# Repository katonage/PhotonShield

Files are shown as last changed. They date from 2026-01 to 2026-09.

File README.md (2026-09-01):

# PhotonShield
 
**Photon Shield assembly for low-noise visual stimulation during two-photon imaging in mice**

This repository contains the 3D CAD models of the **Photon Shield**, a modular optical shielding system designed for two-photon calcium imaging experiments combined with visual stimulation in mice.
- Minimize stray-light contamination in a reproducible way
- Simple manufacturing and use
- Suitable for awake recordings
- Compatible objectives:
   - Olympus 10XSVMP 10×
   - Nikon CFI75 LWD16× W 
   - Olympus XLUMPlanFLN 20×

Detailed experimental validation, benchmarking, and use cases are described in the accompanying publication.

**Citation notice:** If you use or modify these models, please cite the following publication:  
> G. Katona, A. Slézia, A. Dávid, Á. Petik, D. Hillier, I. Ulbert, A. Kaszás <br>
> **3D Printed Photon Shield Assembly for Low-Noise Visual Stimulation During Two-Photon Imaging in Mice.** <br>
> Advanced Materials Technologies (2026): e71290. <br>
> [https://doi.org/10.1002/admt.71290](https://doi.org/10.1002/admt.71290) 

---

## Repository contents

The repository includes CAD models for:

- Headplate
- Two-part cylindrical objective shield
- Objective-mounted top shielding (“Sombrero”)
- Home-cage protection cap
- Custom holder rod and clamp

## Headholder for shield and probe wide v4mod

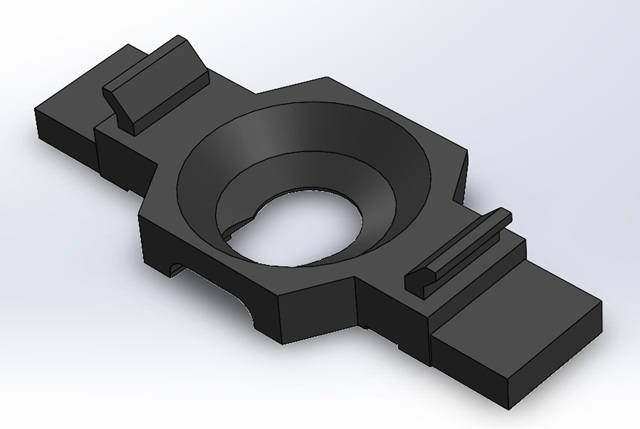
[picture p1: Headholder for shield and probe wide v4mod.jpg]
Headholder for shield and probe wide v4mod


This is the headplate with rails for mounting „Shield Back 10XSVMP v4” and „headholder cap derived v4”. Bottom has opening for a 5 mm coverslip. 

**Important:**  
Care must be taken not to put glue or cement to the top edge of the headplate.

## Shield Back 10XSVMP v4

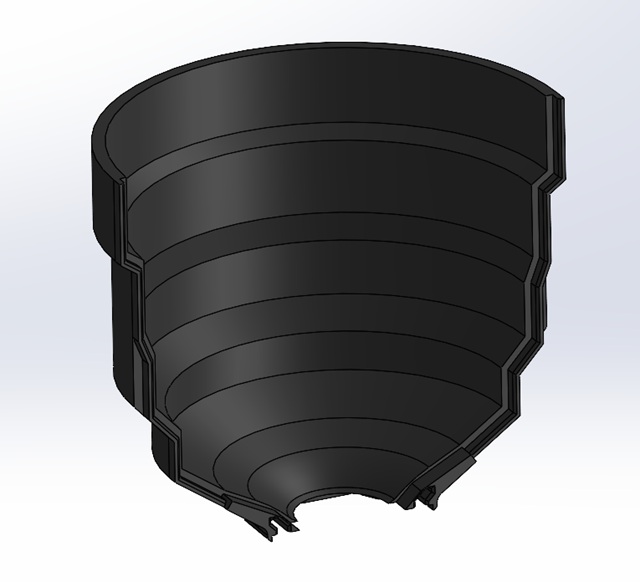
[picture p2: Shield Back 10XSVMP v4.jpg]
Shield Back 10XSVMP v4


This is one side of the shield cylinder that should be mounted first onto the headplate. It is typically mounted from the back of the animal. After mounting, immersion gel can be applied generously.

## Shield Front 10XSVMP derived v4

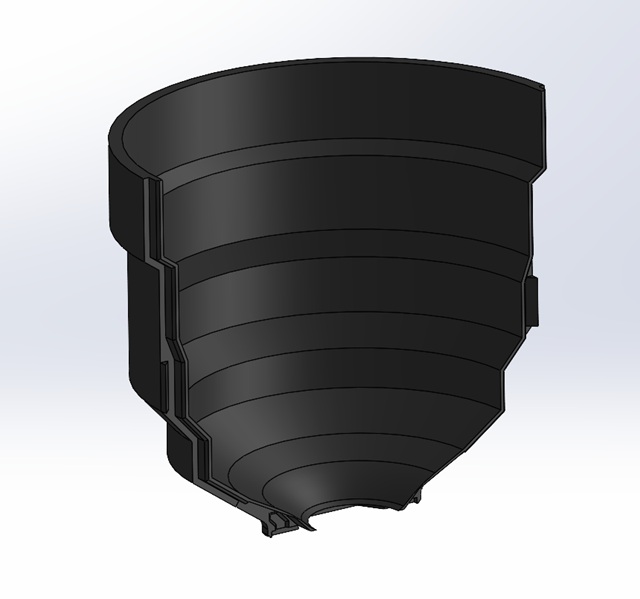
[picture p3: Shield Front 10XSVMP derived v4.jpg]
Shield Front 10XSVMP derived v4


This is the complementary part of the shield cylinder. Attach a ~20 cm long piece of black insulating tape to its outer surface, allowing it to overhang on both sides. After precise insertion, the overhanging parts are smoothed over from both sides to adhere to the other half of the shield. During the process, the microscope’s green illumination is used to make any misalignment visible.

## Headholder cap derived v4

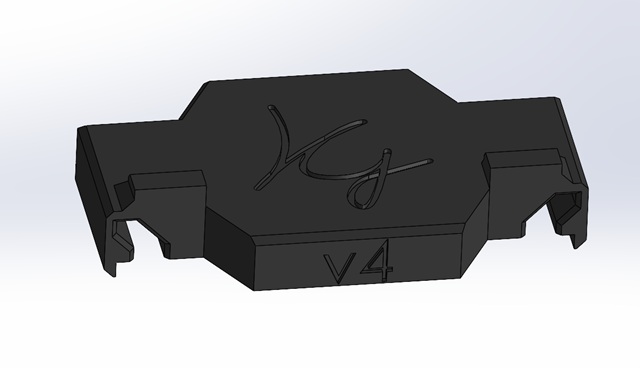
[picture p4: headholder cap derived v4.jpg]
Headholder cap derived v4


This part is fitted onto the headplate when the animal is returned to its home cage.

## Sombrero 10XSVMP v3

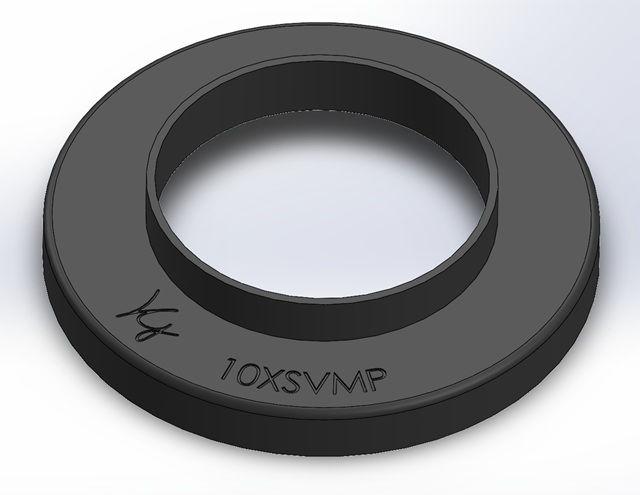
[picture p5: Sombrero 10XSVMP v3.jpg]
Sombrero 10XSVMP v3


This is the top shielding component. It must be slid onto the objective from the rear before operation.

## Sombrero XLUMPlanFLN 20x

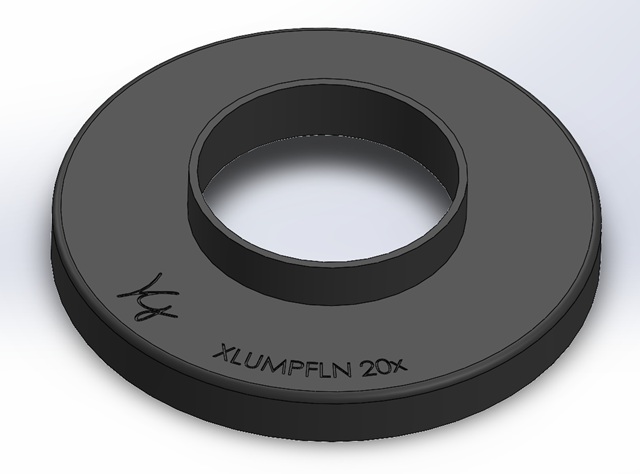
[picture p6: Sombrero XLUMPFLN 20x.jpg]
Sombrero XLUMPFLN 20x


This variant of the top shield fits both:

- **Olympus XLUMPlanFLN 20×**
- **Nikon CFI75 LWD16× W**

As with the other Sombrero design, it must be slid onto the objective from the rear prior to imaging.

## Holder rod (wide v3)

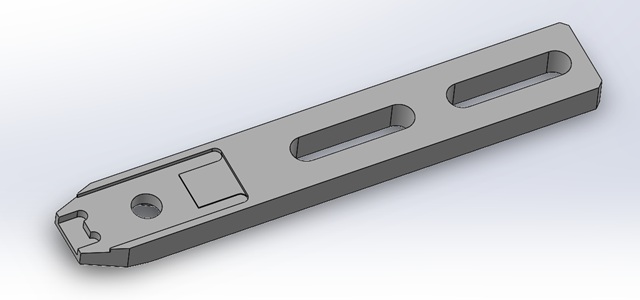
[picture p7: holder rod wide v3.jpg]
Holder rod wide v3


This is the clamp used to hold the headplate. It was custom machined from stainless steel. For anesthetized applications, it can also be 3D printed (select the appropriate configuration inside the model). 

## Holder clamp (wide v2)

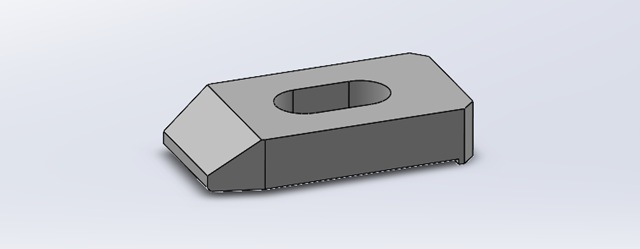
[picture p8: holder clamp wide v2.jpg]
Holder clamp wide v2


This is the jaw that must be used with the holder clamp. It was custom machined from stainless steel.

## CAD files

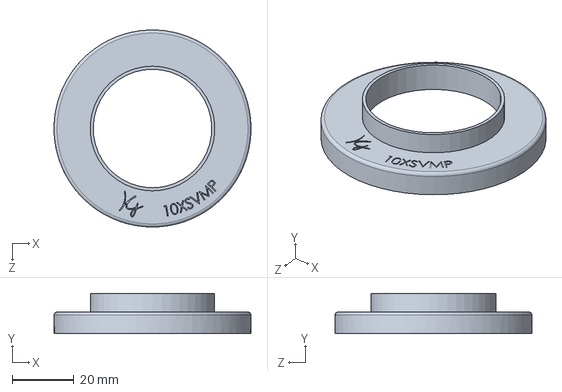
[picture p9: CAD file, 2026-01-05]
Sombrero 10XSVMP v3.SLDPRT
64.0 x 13.0 x 64.0 mm

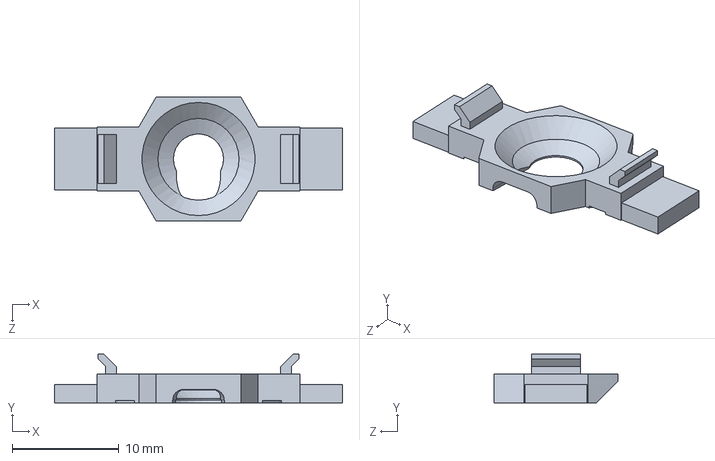
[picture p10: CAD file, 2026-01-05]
Headholder for shield and probe wide v4mod.SLDPRT
27.0 x 4.55 x 11.6 mm

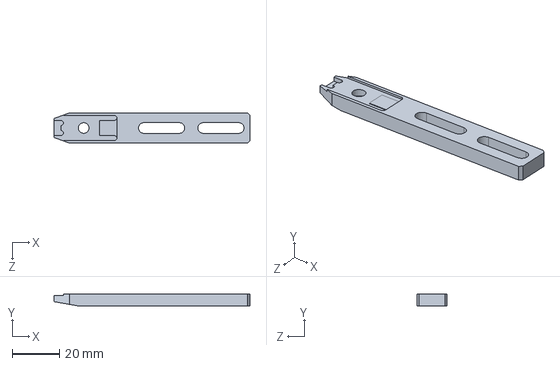
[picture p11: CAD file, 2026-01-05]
holder rod wide v3.SLDPRT
82.6 x 5.00 x 12.8 mm

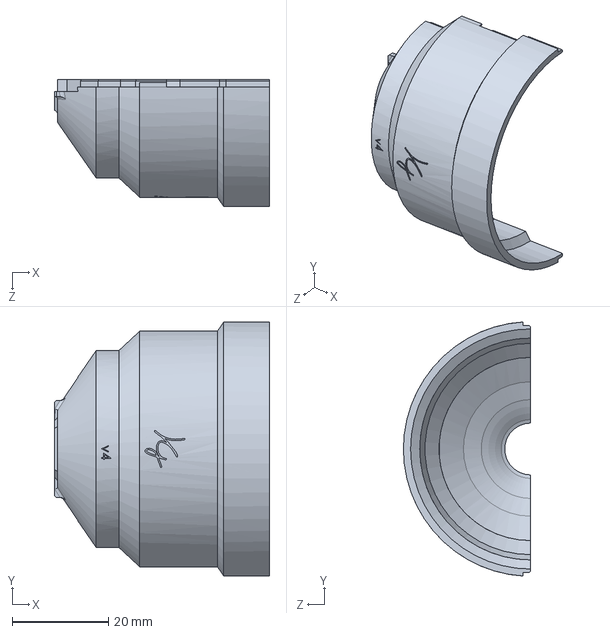
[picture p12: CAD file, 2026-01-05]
Shield Front 10XSVMP derived v4.SLDPRT
44.8 x 52.9 x 26.5 mm

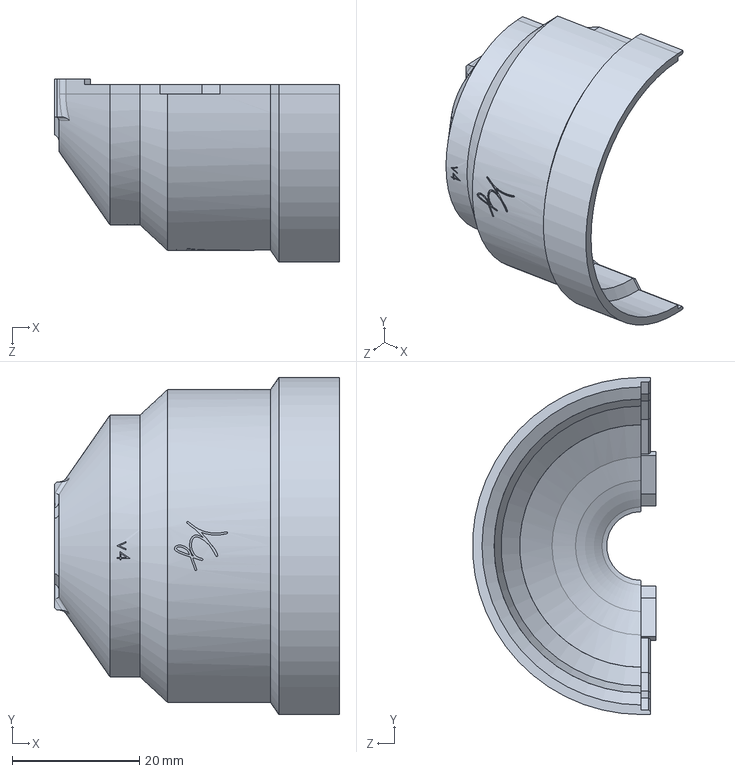
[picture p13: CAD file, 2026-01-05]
Shield Back 10XSVMP v4.SLDPRT
44.8 x 53.0 x 28.9 mm

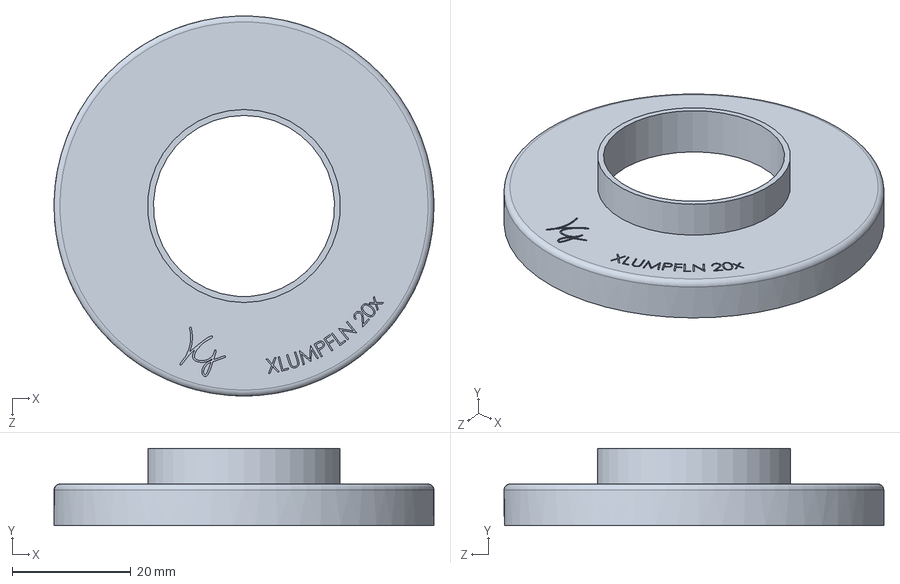
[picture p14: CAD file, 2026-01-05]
Sombrero XLUMPFLN 20x.SLDPRT
64.0 x 13.0 x 64.0 mm

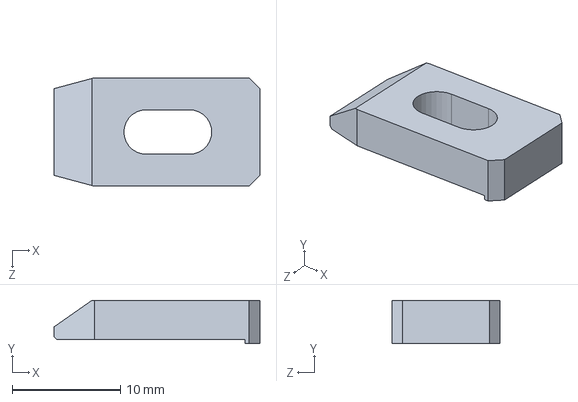
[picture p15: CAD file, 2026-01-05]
holder clamp wide v2.SLDPRT
19.0 x 4.00 x 10.0 mm

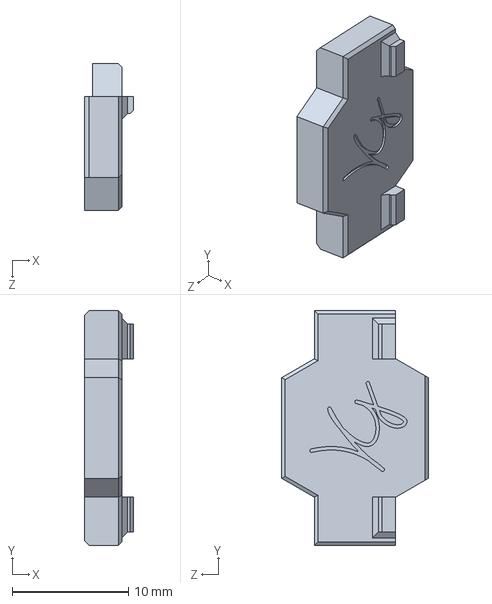
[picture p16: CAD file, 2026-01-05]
headholder cap derived v4.SLDPRT
4.20 x 20.2 x 12.6 mm

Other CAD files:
Headholder for shield and probe wide v4mod.STL
Shield Back 10XSVMP v4.STL
Shield Front 10XSVMP derived v4.STL
Sombrero 10XSVMP v3.STL
Sombrero XLUMPFLN 20x.STL
headholder cap derived v4.STL
